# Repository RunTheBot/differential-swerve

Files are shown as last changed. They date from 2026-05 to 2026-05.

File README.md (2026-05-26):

# Differential Swerve

Swerve Module - But it's differential. 

## What is Swerve Drive?
Swerve drive is a drive train allowing the wheels to be vectored in any direction. The advantage of this is that all the force the motors output goes towards the direction you want to go.

## What is Differential Swerve
A differential swerve allowed for both the drive and steer motors to control both axis. This way, when not turning the wheels both motors are able to contribute going very very fast. Vrooom! 

FRC Build System - Mainly 3D printed and CNC'ed in house

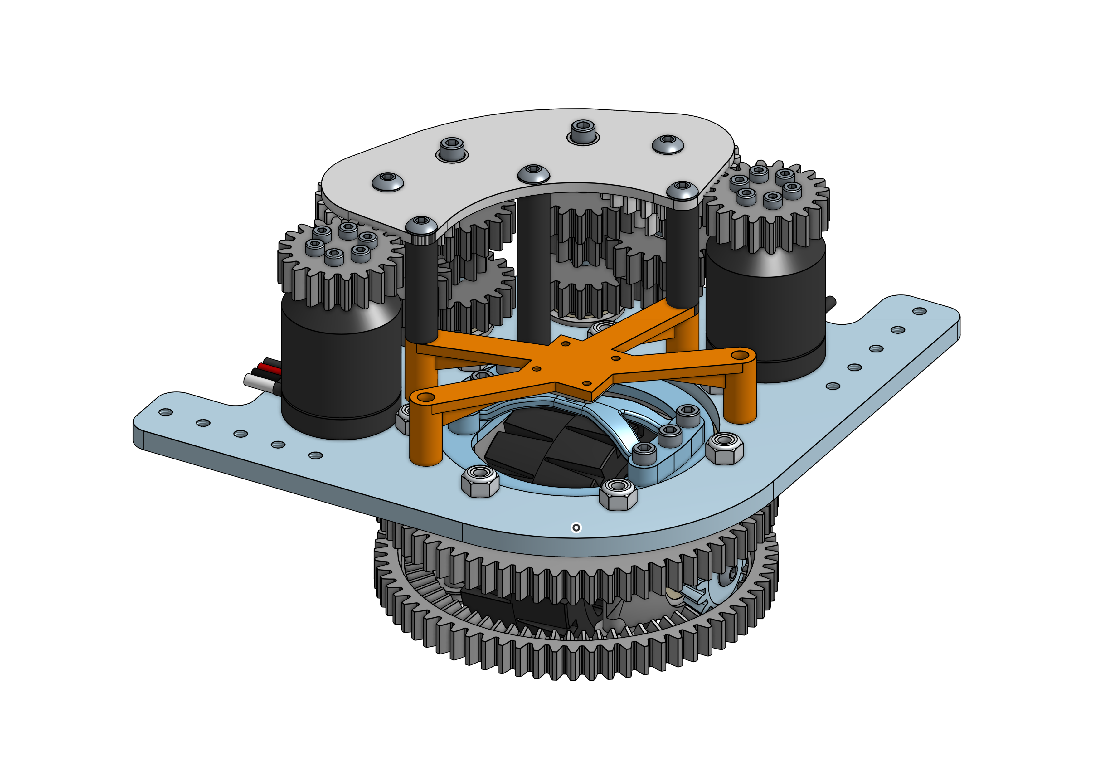
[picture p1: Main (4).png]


# Links
BOM: [BOM](https://docs.google.com/spreadsheets/d/1szEt_mcmtPkUJnaXfoxFZsRM_N5t2wamkg3rPQRiaTA/edit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)

CAD: [CAD](https://cad.onshape.com/documents/5ff0a154606e2ca4a036451a/w/bc440e39d0f320bd08dc1c12/e/1f3ddcda6d7038c73878ab2c)

Software: WPIlib and [7520 - UltimateSwerveBase](https://github.com/Team7520/UltimateSwerveBase)

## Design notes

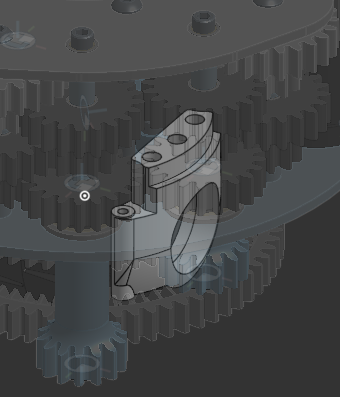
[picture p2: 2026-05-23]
image.png

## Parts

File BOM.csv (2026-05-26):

Item | Subsection Multiplier | Qty per module | Qty | Part Number | Description/Name | Vendor | Qty Per Lot | Price (CAD) | Total | Status | Link
1 | 1 | 1 | 4 | SRV-116 | Driven Diffy Bevel | Custom / 3DP PA-CF | 1 | 0 | 0 | To Be made
2 | 1 | 1 | 4 | REV-21-2423 | 3 ION Traction Wheel (60A | MAXSpline Bore)" | REV Canada | 1 | 8.1 | 32.4 | Waiting | https://revrobotics.ca/ION-Traction-Wheels/?searchid=120514&search_query=REV-21-2423
3 | 1 | 2 | 8 | REV-21-2037 | 1/2 Hex Bore MAXHub" | Custom / 3DP | 1 | 0 | 0 | To Be made
4 | 1 | 1 | 4 | REV-21-1135 | 1/2 Rounded Hex (3.25" L | 13.75mm OD)" | REV Canada | 4 | 33.75 | 33.75 | To Be made | https://revrobotics.ca/.5in-Rounded-Hex-Shafts/?searchid=120515&search_query=REV-21-1135
5 | 1 | 1 | 4 |  | Socket button head cap screw #10-32 x 0.75 | AliExpress | 1 |  | 0 | Availible
6 | 1 | 3 | 12 | REV-21-2805 | #10-32 x 0.5 L Shaft End Screw (V2 | Steel | Black Oxide)" | REV Canada | 25 | 16.2 | 16.2 | Waiting | https://www.studica.ca/en/search?q=REV-21-2805
7 | 1 | 2 | 8 | SRV-101 | Bevel 1.5875000000000001M 63T 75deg | Custom / 3DP | 1 | 0 | 0 | To Be made | N/A (In-house)
8 | 1 | 2 | 8 |  | Bearing Block^3 |  | 1 |  | 0
8.1 | 2 | 4 | 32 | REV-41-1368 | Small Pulley Bearing REV-41-1368 | AliExpress | 20 | $3.50 | $7.00 | Waiting | https://www.aliexpress.com/item/32819002479.html?curPageLogUid=bLfAM8atCllP
8.2 | 2 | 2 | 16 |  | Socket button head screw M3x0.5 x 40 | AliExpress | 50 | 4.31 | 4.31 | Waiting | https://www.aliexpress.com/item/1005002320975566.html?curPageLogUid=ZE7kuhjizy5S
8.3 | 2 | 1 | 8 | SRV-001 | Bearing Block | Custom / 3DP | 1 | 0 | 0 | To Be made | N/A (In-house)
8.4 | 2 | 2 | 16 |  | Hex nut grade A & B M3x0.5 | AliExpress | 50 | 1.32 | 1.32 | Waiting | https://www.aliexpress.com/item/1005008625622586.html?curPageLogUid=M129SZcTZAIQ
8.5 | 2 | 1 | 8 | 1/2 Rounded Hex (13.75mm) ID Bearing (1.125" OD | 0.313" WD | Shielded | Flanged)" | 1/2 Rounded Hex (13.75mm) ID Bearing (1.125" OD | 0.313" WD | Shielded | Flanged)" | REV Canada | 4 | 16.2 | 32.4 | Waiting | https://revrobotics.ca/ION-Bearings/?searchid=120518
8.6 | 2 | 1 | 8 |  | 1/2 Hex Bore Custom Spacer (0.75" OD | 0.375" L)" | Custom / 3DP | 1 |  |  | To Be made
8.7 | 2 | 3 | 24 | 94459A330 | #8-32 x 0.321 L Straight Heat Set Insert" | AliExpress | 50 | 7.5 | 7.5 | Waiting | https://www.aliexpress.com/item/1005007306661746.html
9 | 1 | 1 | 4 | WCP-0357/KA030XP0 | 3 ID X-Contact Bearing (3.5" OD | 0.25" WD)" | AliBaba | 4 | 89.07 | 89.07 | Waiting | Alibaba chats
10 | 1 | 1 | 4 | SRV-002 | Inner Clanp | Custom / 3DP PA-CF | 1 |  |  | To Be made | N/A (In-house)
11 | 1 | 1 | 4 |  | Gearbox |  | 1 |  |  | Waiting
11.1 | 1 | 2 | 8 |  | Motor |  | 1 |  |  | Waiting
11.1.1 | 2 | 6 | 48 |  | Hex socket head cap screw M3x0.50 x 14 | AliExpress | 50 | 4.31 | 4.31 | Waiting | https://www.aliexpress.com/item/1005002320975566.html?curPageLogUid=ZE7kuhjizy5S
11.1.2 | 2 | 1 | 8 | REV-21-1651 | NEO 550 Brushless Motor | REV Canada | 1 | 37.8 | 302.4 | Availible
11.1.3 | 2 | 1 | 8 | SRV-110 | NEO 550 sus Pinion | Custom / 3DP | 1 | 0 | 0 | Waiting | N/A (In-house)
11.2 | 1 | 2 | 8 | 3/8 Rounded Hex (10.25mm) ID Bearing (0.875" OD | 0.28" WD | Shielded | Flanged)" | 3/8 Rounded Hex (10.25mm) ID Bearing (0.875" OD | 0.281" WD | Shielded | Flanged)" | REV Canada | 1 |  |  | Availible | https://revrobotics.ca/ION-Bearings/?searchid=120518
11.3 | 1 | 2 | 8 |  | Socket head cap screw #8-32 x 2.5 | AliExpress | 1 |  |  | Availible | https://www.aliexpress.com/wholesale?SearchText=Socket+head+cap+screw+%238-32+x+2.5
11.4 | 1 | 14 | 56 | R166ZZEE | 0.19 ID Bearing (0.375" OD | 0.156" WD | Shielded | Extended Race)" | AliExpress | 50/10 | 31.99/11.99 | 44 | Waiting | https://www.aliexpress.com/wholesale?SearchText=R166ZZEE+0.19+ID+Bearing+(0.375"+OD | +0.156"+WD | +Shielded | +Extended+Race)"
11.5 | 1 | 2 | 8 | SRV-111 | Input Gear | Custom / 3DP PA-CF | 1 |  |  | To Be made | N/A (In-house)
11.6 | 1 | 2 | 8 | SRV-190 | 0.125in #10 bearing spacer | Custom / 3DP | 1 |  |  | To Be made | N/A (In-house)
11.7 | 1 | 4 | 16 | SRV-112 | Middle gears | Custom / 3DP PA-CF | 1 |  |  | To Be made | N/A (In-house)
11.8 | 1 | 4 | 16 | SRV-190 | functionally a 0.125in #10 bearing spacer | Custom / 3DP | 1 |  |  | To Be made | N/A (In-house)
11.9 | 1 | 2 | 8 | SRV-191 | 0.625in #10 bearing spacer | Custom / 3DP | 1 |  |  | To Be made | N/A (In-house)
11.1 | 1 | 2 | 8 | SRV-192 | ~0..25in #10 bearing spacer | Custom / 3DP | 1 |  |  | To Be made | N/A (In-house)
11.11 | 1 | 2 | 8 | SRV-113 | Output Gears | Custom / 3DP PA-CF | 1 |  |  | To Be made | N/A (In-house)
11.12 | 1 | 5 | 20 |  | Socket button head cap screw #10-32 x 2.5 |  | 1 |  |  | Availible
11.13 | 1 | 1 | 4 | SRV-000 | Top Plate - Main Plate | Custom / CNC 1/4",1" | 0 | 0 | To Be made | N/A (In-house)
11.14 | 1 | 1 | 4 | SRV-150 | Gearbox Plate 3.18 mm | Custom / 3DP | 1 | 0 | 0 | To Be made | N/A (In-house)
11.15 | 1 | 8 | 32 |  | Hex socket head cap screw M3x0.50 x 8 | AliExpress | 50 | 3.21 | 3.21 | Waiting | https://www.aliexpress.com/item/1005002320975566.html?curPageLogUid=ZE7kuhjizy5S
11.16 | 1 | 1 | 4 |  | AS5600 | AliExpress | 2 | 4.89 | 9.78 | Waiting | https://www.aliexpress.com/item/1005009897934982.html
11.17 | 1 | 1 | 4 | SRV-151 | Encoder Mount | Custom / 3DP | 1 | 0 | 0 | To Be made | N/A (In-house)
11.18 | 1 | 1 | 4 |  | 0.196 ID Custom Spacer (0.375" OD | 2.25" L)" | Custom / 3DP | 1 |  |  | To Be made | https://www.aliexpress.com/wholesale?SearchText=0.196+ID+Custom+Spacer+(0.375"+OD | 2.25"+L)"
11.19 | 1 | 2 | 8 |  | 0.196 ID Custom Spacer (0.375" OD | 1.438" L)" | Custom / 3DP | 1 |  |  | To Be made | https://www.aliexpress.com/wholesale?SearchText=0.196+ID+Custom+Spacer+(0.375"+OD | 1.438"+L)"
12 | 1 | 1 | 4 | SRV-001 | Spacer Ring Thing | Custom / 3DP PA-CF | 1 |  |  | To Be made | N/A (In-house)
13 | 1 | 10 | 40 |  | Socket button head cap screw #10-32 x 0.625 |  | 1 |  |  | Availible | https://www.aliexpress.com/wholesale?SearchText=Socket+button+head+cap+screw+%2310-32+x+0.625
14 | 1 | 7 | 28 | 90631A411 | #10-32 Nylon-Insert Locknut |  | 1 |  |  | Availible | https://www.aliexpress.com/wholesale?SearchText=90631A411+%2310-32+Nylon-Insert+Locknut
15 | 1 | 6 | 24 |  | Socket head cap screw #8-32 x 0.5 |  | 1 |  |  | Availible | https://www.aliexpress.com/wholesale?SearchText=Socket+head+cap+screw+%238-32+x+0.5
16 | 1 | 1 | 4 | WCP-0911 | 3/8 Rounded Hex (1.435" L | 10.25mm OD)" | WCP | 1 |  |  | To Be made
17 | 1 | 1 | 4 | WCP-0911 | 3/8 Rounded Hex (2.444" L | 10.25mm OD)" | WCP | 1 |  |  | To Be made | Search required
18 | 1 | 1 | 4 | SRV-114 | Diffy Pinion Short | Custom / 3DP PA-CF | 1 |  |  | To Be made | N/A (In-house)
19 | 1 | 1 | 4 | SRV-115 | Diffy Pinion Long | Custom / 3DP PA-CF | 1 |  |  | To Be made | N/A (In-house)
20 | 1 | 1 | 4 | SRV-152 | Encoder Magnet Mount | Custom / 3DP | 1 |  |  | To Be made | N/A (In-house)
Manufacturing |  |  | 0 |  | Aluminum Metal (Probably Purchesed in bulk with team overestimate) |  |  |  | 100 | Waiting
Manufacturing |  |  | 0 |  | Fiberon™ PA612-CF15 |  |  |  | 47.99 | Waiting | https://shop.polymaker.com/products/fiberon-pa612-cf?variant=43594432282681
Assembly |  |  | 0 |  | Parts in layout provided by team (Scraps/Dedicated project parts) |  |  |  |  | Availible

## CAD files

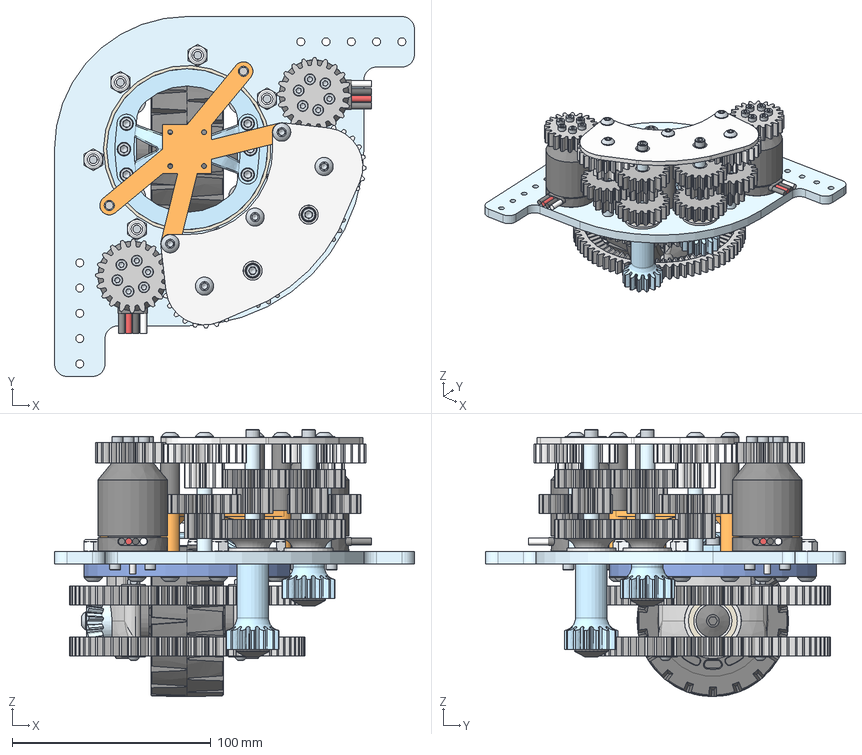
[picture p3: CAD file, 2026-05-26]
CAD/Main.step
181.0 x 181.0 x 134.3 mm
#10-32 Nylon-Insert Locknut x 7
Socket button head cap screw #10-32 x 0.625 x 10
Spacer Ring Thing
Inner Clanp
Bevel 1.5875000000000001M 63T 75deg x 2
Driven Diffy Bevel
Socket head cap screw #8-32 x 0.5 x 6
3/8" Rounded Hex (2.444" L, 10.25mm OD)
1/2" Hex Bore MAXHub (Aluminum) x 2
3/8" Rounded Hex (1.435" L, 10.25mm OD)
#10-32 x 0.5" L Shaft End Screw (V2, Steel, Black Oxide) x 3
Diffy Pinion Long
Encoder Magnet Mount
Diffy Pinion Short
3" ID X-Contact Bearing (3.5" OD, 0.25" WD)
3" ION Traction Wheel (60A, MAXSpline Bore)
1/2" Rounded Hex (3.25" L, 13.75mm OD)
1/2" Rounded Hex (13.75mm) ID Bearing (1.125" OD, 0.313" WD, Shielded , Flanged) x 2
1/2" Hex Bore Custom Spacer (0.75" OD,0.375" L) x 2
#8-32 x 0.321" L Straight Heat Set Insert x 6
Bearing Block x 2
Socket button head screw M3x0.5 x 40 x 4
Inner Race x 8
Outer Race x 8
Hex nut grade A & B M3x0.5 x 4
Socket button head cap screw #10-32 x 0.75
Middle gears x 4
0.19" ID Bearing (0.375" OD, 0.156" WD, Shielded, Extended Race) x 14
0.125in #10 bearing spacer x 2
Gearbox Plate 3.18 mm
0.196" ID Custom Spacer (0.375" OD,1.438" L) x 2
3/8" Rounded Hex (10.25mm) ID Bearing (0.875" OD, 0.281" WD, Shielded , Flanged) x 2
0.625in #10 bearing spacer x 2
Output Gears x 2
Hex socket head cap screw M3x0.50 x 8 x 8
Socket button head cap screw #10-32 x 2.5 x 5
0.196" ID Custom Spacer (0.375" OD,2.25" L)
~0..25in #10 bearing spacer x 2
functionally a 0.125in #10 bearing spacer x 4
Hex socket head cap screw M3x0.50 x 14 x 12
NEO 550 sus Pinion x 2
NEO 550 Brushless Motor x 2
AS5600
Input Gear x 2
Socket head cap screw #8-32 x 2.5 x 2
Encoder Mount
Top Plate - Main Plate

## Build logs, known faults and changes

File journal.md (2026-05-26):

---
title: "Diffy Swerve Drive"
author: "RunTheBot"
description: "Mostly 3D printed differential swerve"
created_at: "2025-06-17"
---
# Journal

Hours: 31 hours

# May 15th

Time Spent: 6 hours

The FRC Season is over so I have too much time on hand. Lets make a diffy swerve!

## Research
I am basing my design on exsiting "Pod Archetypes". I mainly looked at VEXU COMET's [research](https://doi.org/10.31224/5757). I also already have assembled MK4i, MK4n, and MK5n swerve modules so I took inspo from there.

## Design
After ~1h of research I got started on design. I wanted to use a 2.5in colson but, VEX shut down their VEX Pro product line so no colsons and no 2.5 in. I opted for a 3in gobuilda wheel instead.

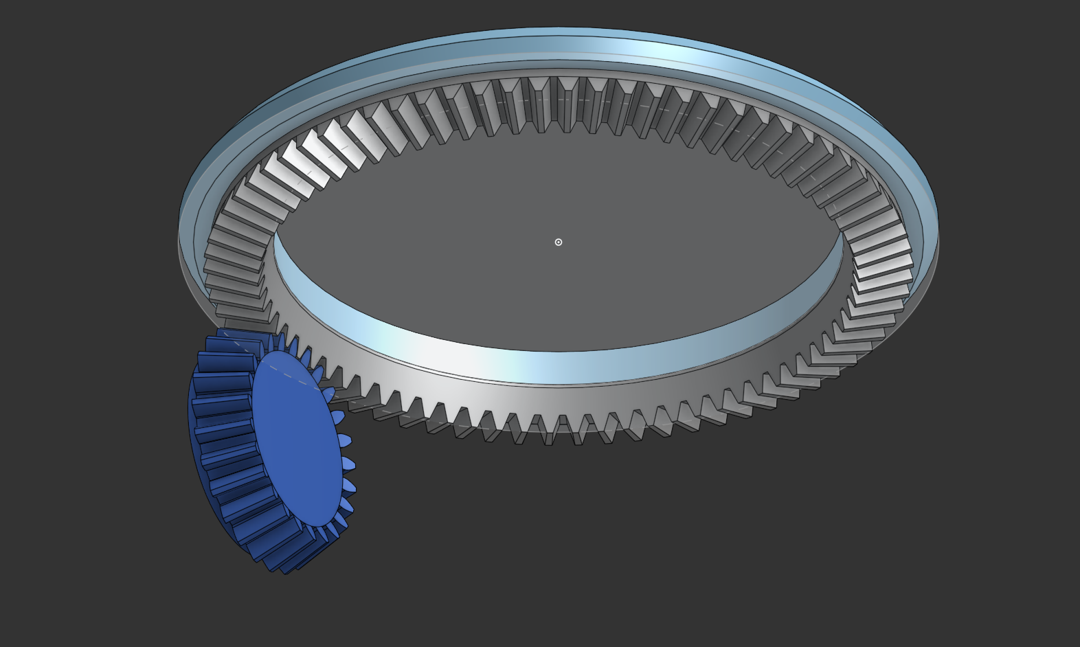
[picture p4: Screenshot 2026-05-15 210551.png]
Base Bevel Gears


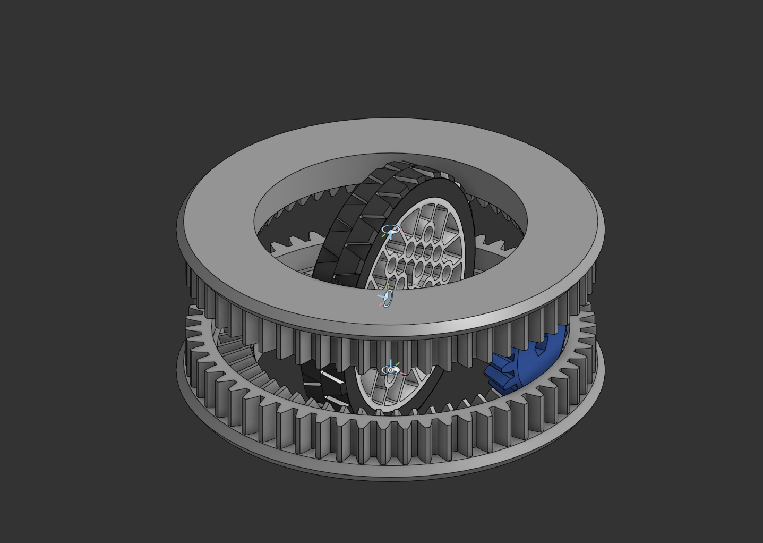
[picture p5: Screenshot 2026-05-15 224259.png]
V1

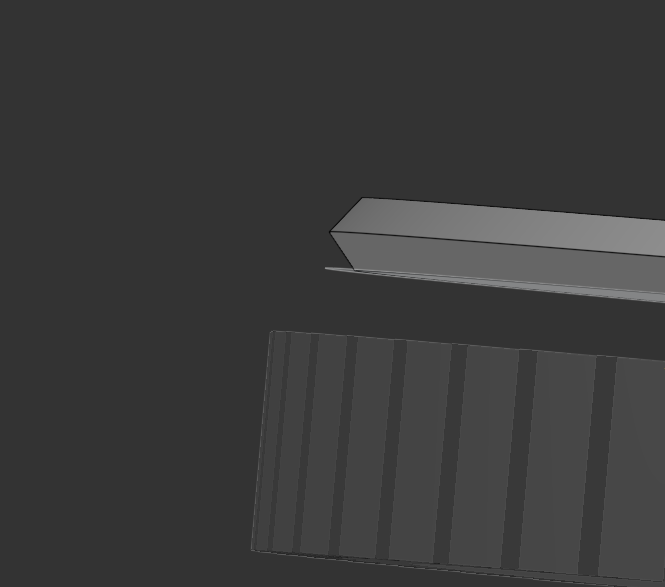
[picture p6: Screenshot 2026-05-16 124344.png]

### It's now 2 AM so kinda May 16th?

I decided to switch wheels, I'm using MAX Traction wheels from REV Robotics now. 

I also made the top plate a seperete V slot so it can hold the wheel and I made the top gear have a internal V-slot. (This will later change a lot). V1 of the pod is now done.
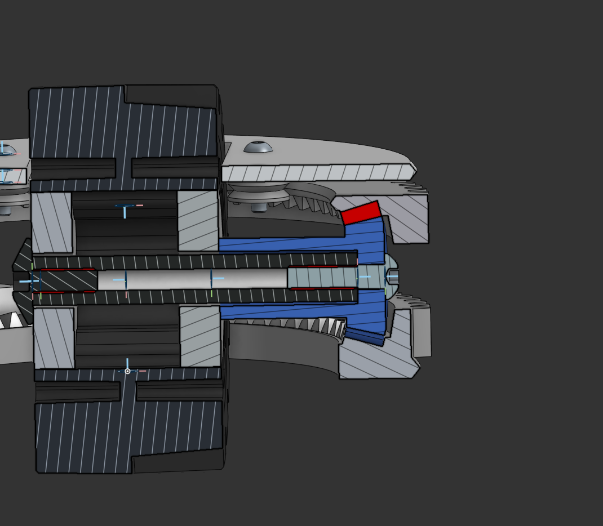
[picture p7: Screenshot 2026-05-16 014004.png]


# May 16th and 17th

Hours: 6h 

## Design
Starting to change the top plate already... Sliming it down first and finding a way to attach the bearing. 

Because the bearing block will hold the entire weight of the robot I decided to run it through simulations. I dabled in shape optimization.

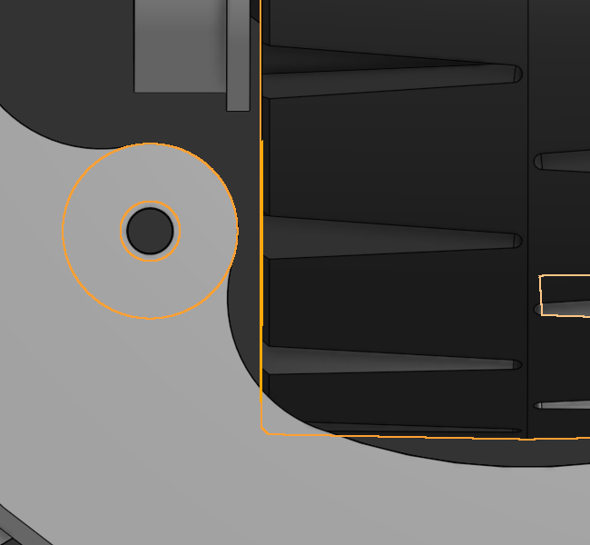
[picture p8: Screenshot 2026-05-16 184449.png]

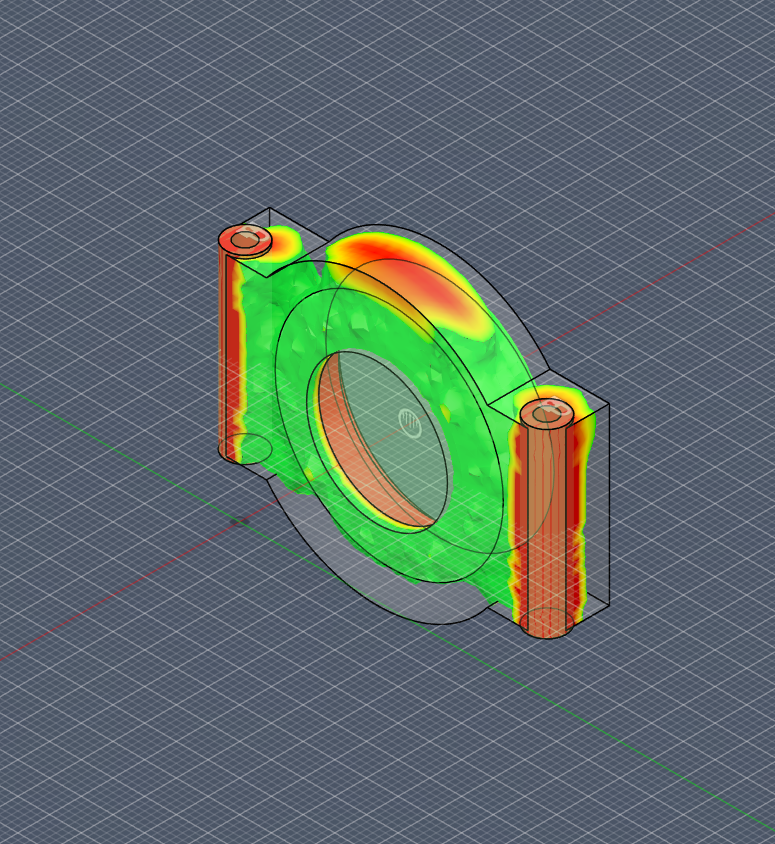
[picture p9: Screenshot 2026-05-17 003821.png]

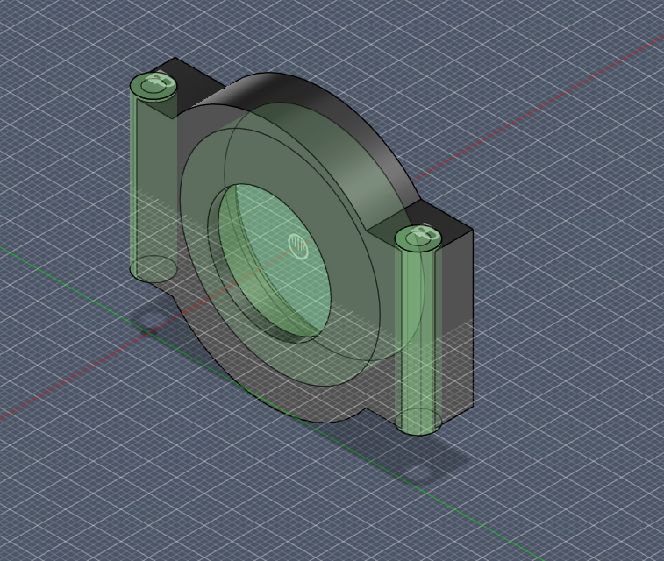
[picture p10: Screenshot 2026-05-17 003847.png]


My design sucks so time to restart. V2 just gives a direct path for forces to travel. inspired by SDS's Bearing blocks on the MK5 series.

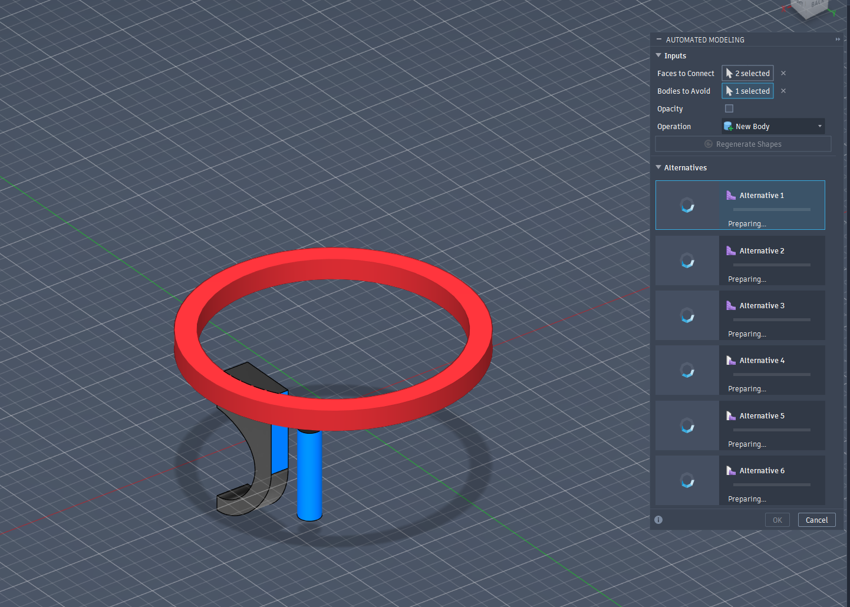
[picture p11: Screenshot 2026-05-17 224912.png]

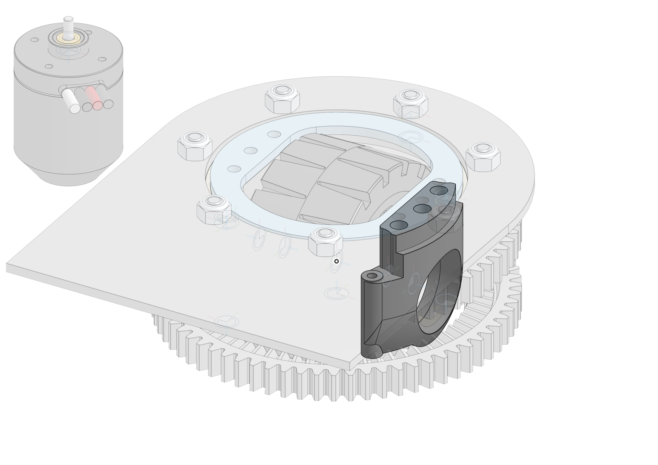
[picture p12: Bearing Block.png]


In this iteration I also swapped to x contact bearing as I do not believe in the v slot with 3d prints staying ridged so yeah.

The design is made with a circle and a sphere and is quite elegant. Fits well good packaging and have not changed it since.

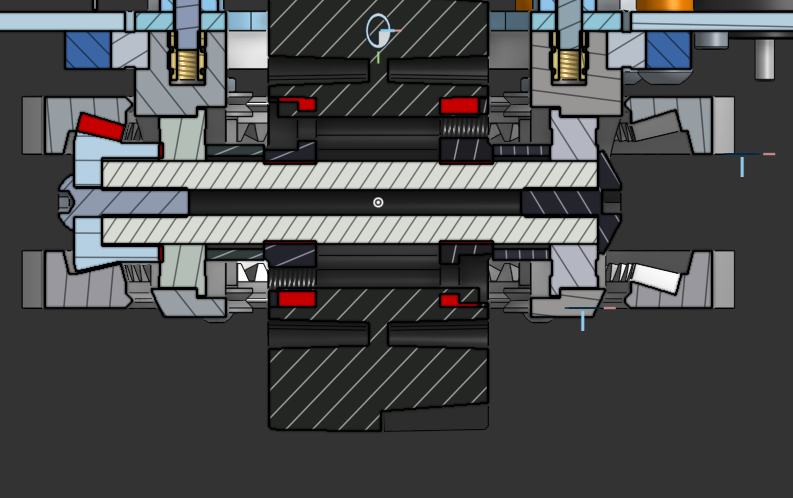
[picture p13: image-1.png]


# May 18th 

Hours: 6h 

It's Victoria Day!

Time to spend 6 hours crashing out about a gearbox! and just improving things all round

## Gearbox V1 
It was so trash. it was a bunch of sketches and maybe some gears but after like 2 hours of trying I restarted. No images cuz it wasnt much

## Gearbox V2
This one came to life and the packaging was okay. It was based on 4 cylyders and it worked. Took me another 2 ish hours 😭. I then added mounting onto the main plate and it was "done". 

It's fat... really fat... bigger than the MK4's because of my choice of motor, the Neo 550, spins at 11000 RPM and needs a lot of reduction.

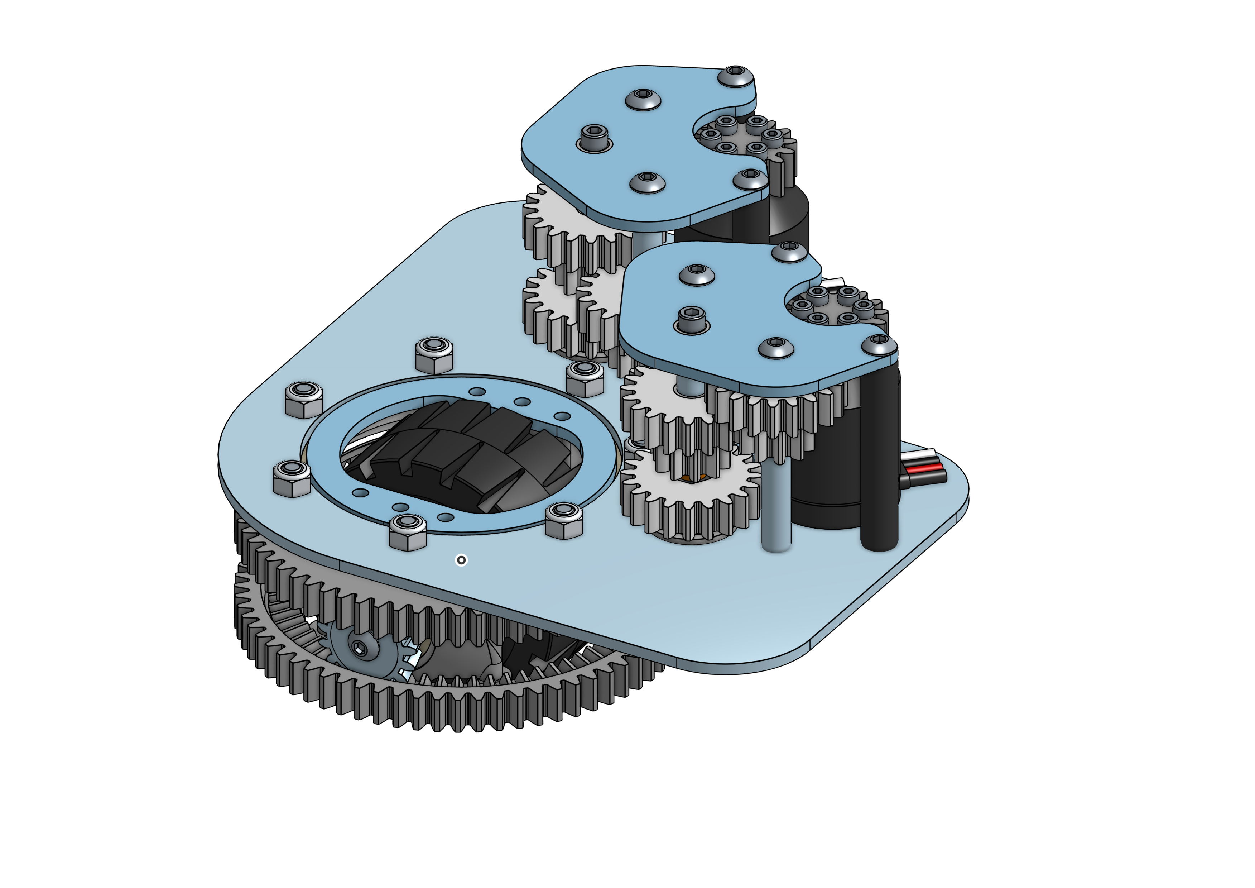
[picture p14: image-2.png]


# May 20th and 21st

hours: ~2h

## Gearbox V3
I didn't stay up over night this time. I just decided to bundle it cuz it was all V3 of gearbox.

This time I wrapped it around the center of the module. Far more space effective. I also reused one of the screws putting two gears on one, more efficient.

Yay it fits nicely now, smaller than a mk4i.
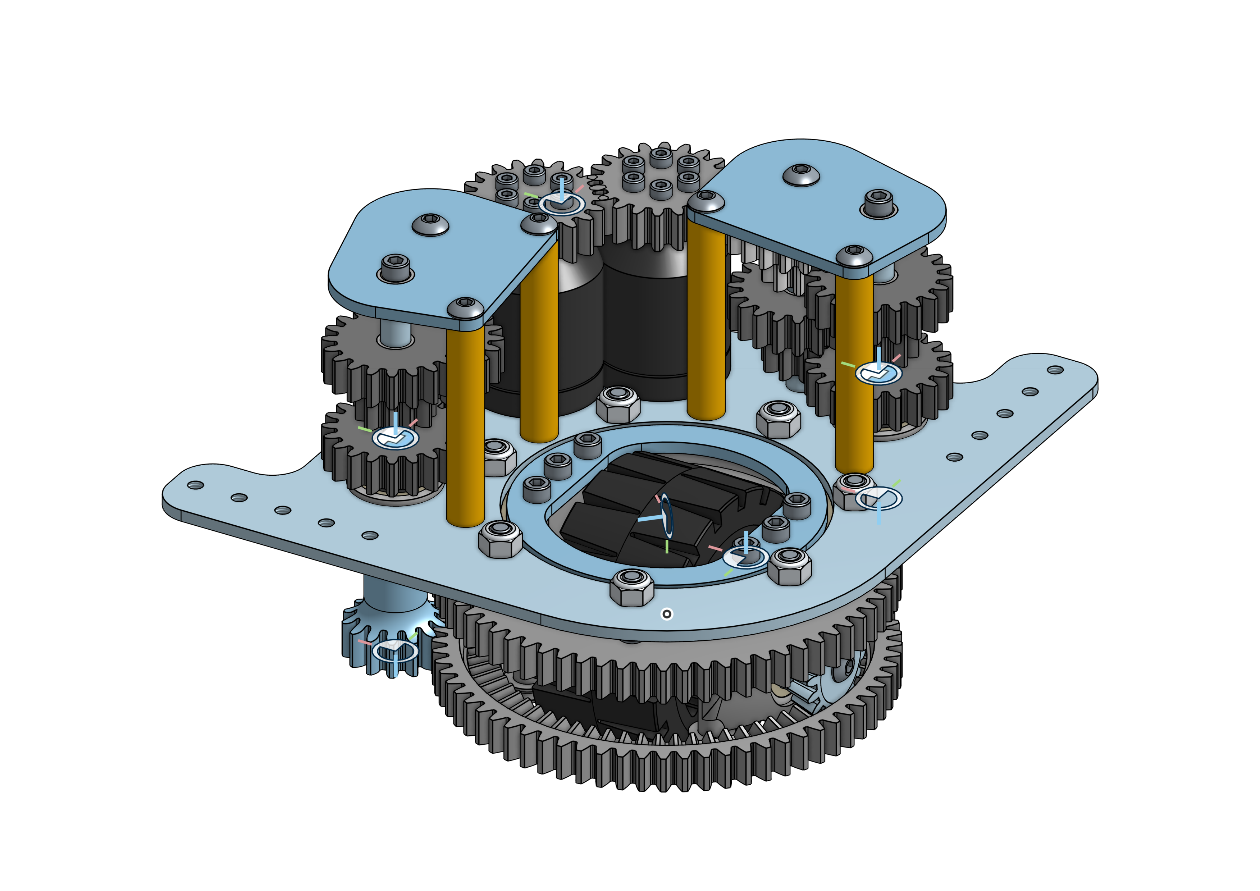
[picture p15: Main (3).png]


# May 21st
Time Spent: ~2h
After finishing V3 I decided to lay out the actual robot. Fixed some intersecting parts nothing notable.

# May 22
Time Spent: ~4 hours

I continued fixing intersecting parts. And we're back to the gearbox...

## Gearbox V3.5
Yay not a full version!!! Cuz I basically just redid the top plate and flipped the mounting to fit better.

## Hall Effect Encoder

Whoops almost forgot that one. I added a magnetic encoder to know where the wheel is. Side note: why does the generic as5600 breakout have like no docs?

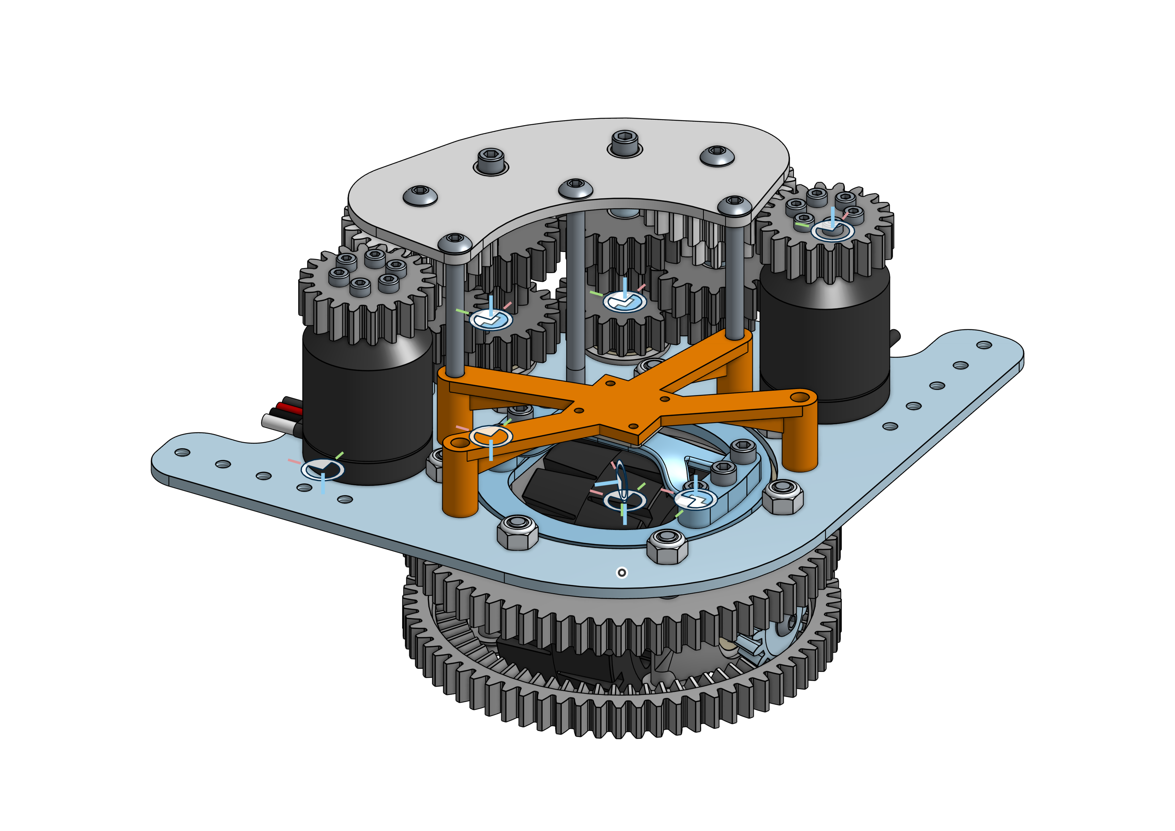
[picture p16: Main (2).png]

# May 23rd

Time Spent: 1 hour
I did this journal. I love procrastinating journal.

# May 24th
Time Spent: 2 hours

More gearbox changes. Adjusted angles and adding more tolerance.  
More Encoder changes. Adding more tolerance.

# May 25th
Time Spent: 2 hour

BOM... Thats it

and submitted the project.
